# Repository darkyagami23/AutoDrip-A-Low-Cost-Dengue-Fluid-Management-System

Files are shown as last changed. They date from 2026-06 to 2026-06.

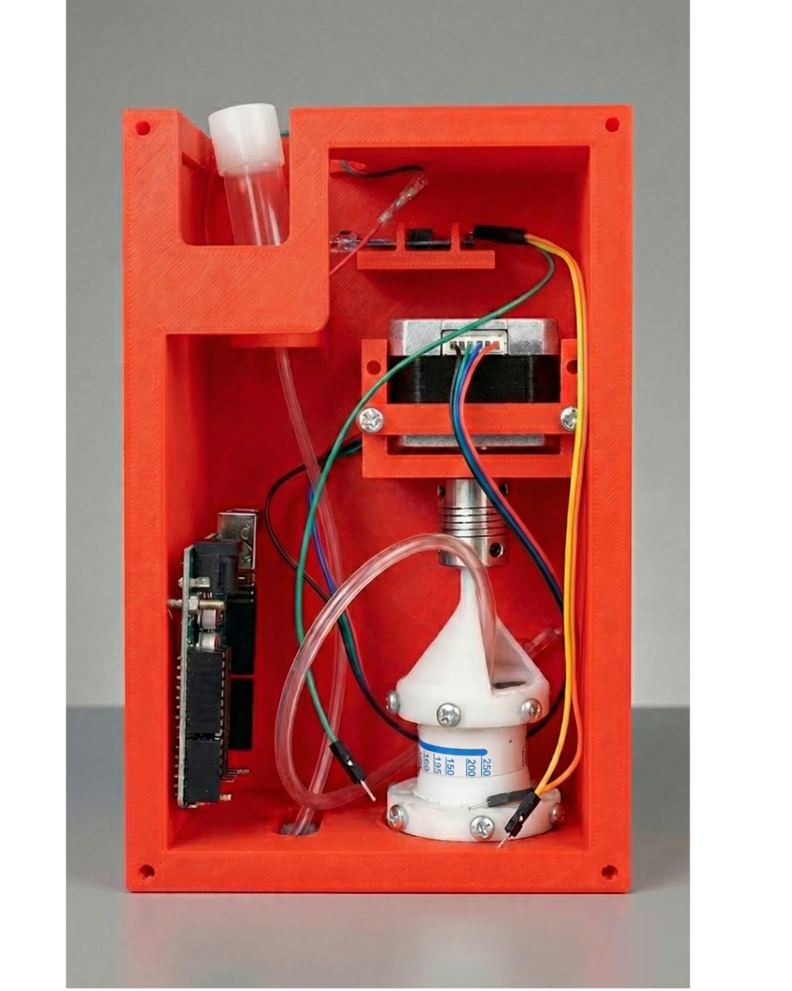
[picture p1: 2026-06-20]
docs/inside the box.jpg

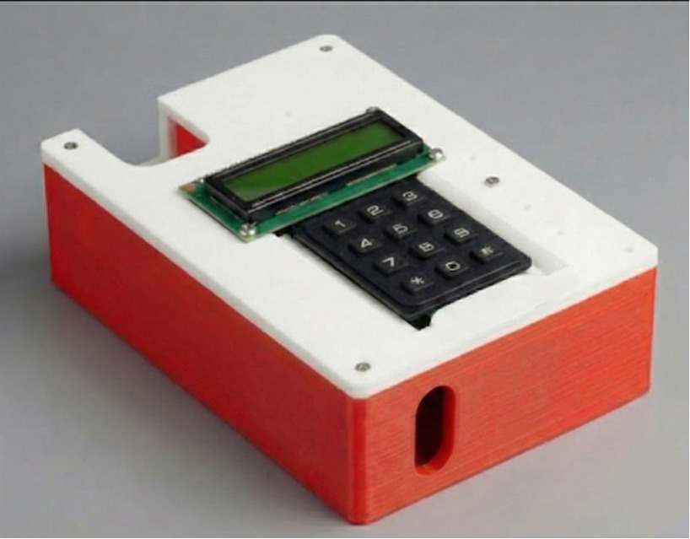
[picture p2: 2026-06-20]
docs/outside the box.jpg

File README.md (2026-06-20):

# AutoDrip: A Low-Cost Dengue Fluid Management System

## Overview
AutoDrip is a low-cost, gravity-driven automated controller designed to calculate required flow rates and regulate clinical flow rates for Group B dengue patients. The device ensures accurate, safe, and standardized intravenous (IV) fluid delivery in resource-constrained healthcare environments. 

## System Architecture
The system integrates four primary components:
*   A flow calculator based on national dengue guidelines.
*   A non-contact infrared (IR) drop sensor.
*   A stepper-actuated flow regulator (Nema 17).
*   A binary search-based feedback algorithm.

## Hardware Requirements
*   Microcontroller (e.g., ESP32 / Arduino)
*   Nema 17 Stepper Motor (17HS4401S)
*   Non-contact IR Sensor (LED emitter and photodiode receiver)
*   Standard Dial Flow Meter
*   3D Printed Parts: Conical Coupler and Fixer (Files located in `/CAD`)

## Software Installation
1. Clone this repository.
2. Open the `/firmware` directory in your preferred IDE.
3. Flash the firmware to the microcontroller. 

## Citation
If this project aids your research, please cite the original ICME 2025 paper:
> Ahasan, M. M., Shaikh, N. A., Himel, S. S., & Ahmed, M. T. (2025). *AutoDrip: A Low-Cost Dengue Fluid Management System*. 15th International Conference on Mechanical Engineering (ICME 2025).

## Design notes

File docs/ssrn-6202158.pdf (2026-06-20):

ICME 2025

Paper ID 286 – 1

# AutoDrip: A Low-Cost Dengue Fluid Management System

## Mir Mashrafi Ahasan¹, a), Nuzhat Aisha Shaikh¹, b), Sadman Sakib Himel ¹, c) and Md. Tazuddin Ahmed¹, d)

1Department of Biomedical Engineering, Bangladesh University of Engineering and Technology, Dhaka-1205, Bangladesh

a) Corresponding author: 2018023@bme.buet.ac.bd b)2018022@bme.buet.ac.bd
c)2018013@bme.buet.ac.bd
d) mdtuahmed@bme.buet.ac.bd Abstract. Dengue fever is a major health concern in subtropical regions, where severe cases require precise intravenous (IV) fluid therapy to prevent life-threatening complications. In resource-limited settings, manual drip regulation is error-prone due to staff shortages and inadequate monitoring. AutoDrip, an automated gravity-driven fluid management system, is presented to calculate the required flow rate (RFR) and regulate the clinical flow rate (CFR) for dengue patients. The device combines a stepper motor–driven flow controller, a non-contact infrared (IR) drop sensor, and a binary search–based feedback algorithm. System performance was evaluated under dengue IV therapy protocols. The RFR calculation achieved 100% accuracy, drop count accuracy averaged 98.3%, and CFR regulation reached 99.3% accuracy, stabilizing within 7-9 iterations. These results demonstrate that precise and reliable infusion control can be achieved with a low-cost device, making AutoDrip a practical solution to enhance patient safety and reduce clinical workload during dengue outbreaks.

KEY WORDS: Automated IV therapy, Dengue fluid management, Medical device automation, Healthcare resource optimization, Point-of-care technology

### 1. INTRODUCTION

Dengue is a major public health concern in tropical regions such as Bangladesh, with 321,073 cases recorded in 2023—the country’s largest outbreak to date [1]. Severe cases require precise intravenous (IV) fluid therapy, yet manual regulation with gravity sets is highly error-prone, often deviating by ±20–25%, particularly during patient surges that strain nursing capacity. Infusion pumps provide accurate delivery but remain costly and impractical in resource-limited settings.

Several automated infusion systems have been proposed, using optical, ultrasonic, or pressure sensors with servo or peristaltic pump mechanisms [2–4]. Al-Obaidi et al. (2024) developed an Intelligent Saline Controlling Valve utilizing a Mamdani fuzzy inference system to autonomously regulate intravenous fluid rates and prevent air embolisms by monitoring drip speed, pressure, and bubble presence [5]. Pabitha and Selvakumar (2025) proposed an IoT-enabled architecture facilitating real-time remote monitoring of IV fluid levels and automated alerting via a mobile application [6]. Gravity-based solutions such as AccuDrip demonstrate improved stability over manual regulation [7]. However few designs specifically target dengue requirements or include formal tolerance and convergence analysis. To address this gap, we propose AutoDrip, a low-cost, gravity-driven automated controller. The system integrates (i) a flow calculator based on national dengue guidelines, (ii) a non-contact infrared drop sensor, (iii) a stepper-actuated flow regulator, and (iv) a binary search–based feedback algorithm. AutoDrip is designed to ensure accurate, safe, and standardized fluid delivery for Group B dengue patients in resource-constrained healthcare environments.

15th International Conference on Mechanical Engineering 17-18 December 2025, BUET, Dhaka, Bangladesh

Available on SSRN. SSRN is an open-access online preprint community, owned by Elsevier.

This preprint research paper has not been peer reviewed. Electronic copy available at: https://ssrn.com/abstract=6202158

# Preprint not peer reviewed

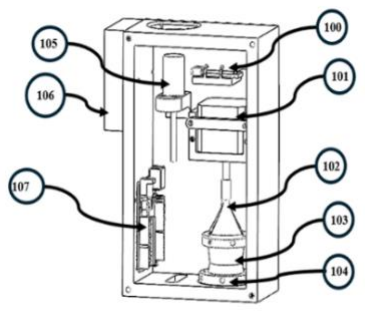
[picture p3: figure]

Paper ID 286 – 2

### 2. METHODOLOGY

### 2.1 FLOW RATE CALCULATION

### 2.1.1 Clinical Classification of Dengue Patients

Dengue, an arboviral disease, istransmitted by Aedes mosquitoes. Patients are stratified as Group A (mild), Group B (warning signs or risk factors requiring hospitalization), and Group C (severe, needing intensive care) [8,9]. This system targets Group B dengue patients, who require guided IV fluid therapy based on national clinical guidelines [8-10].

### 2.1.2 Calculation Principle

For Group B dengue patients, fluid requirement is calculated from demographic and clinical inputs (age, sex, height, body weight, blood pressure, capillary refill time, and IV set drip factor). Eligibility is confirmed when pulse pressure >20 mmHg and capillary refill time <2 s [1]. Maintenance fluid is then determined using the Holliday–Segar method, with actual body weight applied when BMI ≤25, otherwise IBW (Ideal Body Weight) is derived from the formula of equation (1) and (2),
Men: 50 + max (0, 0.91 × [Heigℎt (cm)− 152.4]) kg | (1)
Women: 45.5 + max (0, 0.91 × [Heigℎt (cm)− 152.4]) kg | (2)
Maintenance and Deficit Fluid Requirement
The Holliday–Segar 4-2-1 rule was used: 4 mL·kg⁻¹·h⁻¹ for the first 10 kg, 2 mL·kg⁻¹·h⁻¹ for the next 10 kg, and 1 mL·kg⁻¹·h⁻¹ thereafter. Deficit Fluid Requirement (Oral+IV) for ‘Group-B NS’ patients, a default 5% dehydration is assumed in equation (3):
Deficit fluid (mL) = 50 mL ∙ kg⁻¹ × Wtparam(kg) (3)

Flow rate prescriptions follow the national dengue guideline, with reassessment every 6 hours for at least 48 hours. [9]

### 2.2 FLOWRATE COUNTER

The AutoDrip device monitors IV drip rates using a non-contact infrared (IR) sensor composed of an LED emitter and photodiode receiver. With the fall of each droplet, the LED is interrupted, generating a signal for drop counting. Since drop rates are uniform, continuous long-term monitoring is unnecessary. Tests with different averaging windows (5–20 s) showed that 10 s (Tavg) provides stable and accurate measurement. Drop counts are recorded in drops/s and converted to drops/min for comparison with prescribed rates. This method avoids contamination and integrates seamlessly with standard IV sets without modification.

### 2.3 FLOW CONTROL MECHANISM

The core of the AutoDrip system is its automated flow rate control mechanism, which translates digital calculations into precise mechanical adjustments of the intravenous (IV) fluid flow.
The primary components of the Flow Control Mechanism are:
- Stepper Motor(101): The final AutoDrip device employs a Nema 17 stepper motor (17HS4401S) with 600-step precision for flow control. The stepper, coupled with a custom conical coupler and dial flow meter, ensures reliable and accurate performance.
- Dial Flow Meter (114): The system uses a medically approved rotational dial flow meter to regulate IV tube constriction. While its built-in scale is not used for setting flow rates, the device ensures safe and reliable regulation as part of the AutoDrip system.

FIGURE 1 Isometric View of AutoDrip Device Assembly

# Preprint not peer reviewed

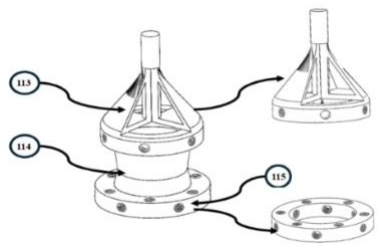
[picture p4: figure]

Paper ID 286 – 3

- Conical Coupler (113): A custom conical coupler connects the stepper motor to the dial flow meter, ensuring balanced torque transfer with minimal friction.
- Fixer (115): To ensure stability and prevent misalignment during rotation, a fixer is used to immobilise the stationary lower part of the dial flow meter assembly within the device housing.

### 2.4 FEEDBACK AND CONTROL ALGORITHM

### 2.4.1 Problem setup

Let θ ε [θmin, θmax]denote the motor angle controlling the tube constriction, and let f(θ) represent the steady-state drop rate measured by the IR sensor (drops/min). The clinical target is ft
. Within the operating region of interest, the mechanism behaves monotonically; that is, if θ1 < θ2

, then f(θ1

) ≥ f(θ2

). The objective is to
determine an angle θt
such that | f(θt

) − ft
| ≤ δ , where δ is a tolerance derived from clinical acceptance. With stepper-driven actuation, the admissible set of angles is shown in equation (4):
Θ = {θmin +kc | k = 0,1,2, ⋯ , N − 1}, N = ⌈

θmax−θmin
∆θ
⌉ | (4)

### 2.4.2 Binary search controller

Define the signed error e(θ) = f(θ) −ft

. With monotonic f(θ), the domain partitions into regions above or below the target. The binary search algorithm proceeds on the index interval [L, R] ⊆ {0,1,2, ⋯ , N − 1}:

1. Initialize L = 0, R = N −1
2. While L ≤ R:
i. M = ⌊

L + R
2

⌋ → set θ = θmin + M∆θ.

ii. Measure f(θ). (Averaged over a window Tavg)
iii. If | f(θt
) − ft

| ≤ δ → return θ
iv. If f(θ) > ft

: increase constriction → set L = M +1
v. Else: decrease constriction → set R = M − 1

### 2.4.3 Stabilisation Time

Each evaluation consists of, Teval = Tmove + Tsettle +Tavg. Each iteration of the algorithm halves the interval, keeping number of measurements K bounded by, ⌈log2 N⌉. Since averaging dominates (Tavg ≈10s window to smooth drop-count noise), the stabilization time, Tbin is bounded by, ⌈log2 N⌉ ∙ Teval .

Illustration for a 300° dial range with ∆θ = 1° where, N ≈ 300, K ≤ ⌈log2 300⌉, Teval ≈ 10s

FIGURE 2 Controller-Coupler Mechanism

FIGURE 3 Internal view (left) and external view (right) of the assembled device

# Preprint not peer reviewed

Paper ID 286 – 4

Tbin ≲ 9 ∗ 10 = 90s | (5)

### 2.4.4 Step-Size Adequacy and Angle-Flow Relation

The binary search algorithm operates in ∆θ = 1° increments, requiring verification that such steps remain within clinical tolerance. Let Q(θ) be the flow rate (mL ∙ ℎ

−1
) and the step size can be determined from equation (6):

S1° = |Q(θ +1°)− Q(θ)|, Smax = max
θ
S1°(θ) | (6)

The step size safety condition is therefore,

Smax ∙ ∆θ ≤ τQt

, τ = 0.05(±5%) | (7)

With Qt being the target flow-rate consistent with infusion pump standards. From the dial curve in fig. 4, Smax ≈ 5 mL ∙ ℎ

−1 near 225–250 mL ∙ ℎ

−1
. Table 2 confirms that increments across 50–250 mL ∙ ℎ
| −1 remain well within
±5%, with deviations only 0.5–2.1% per degree.

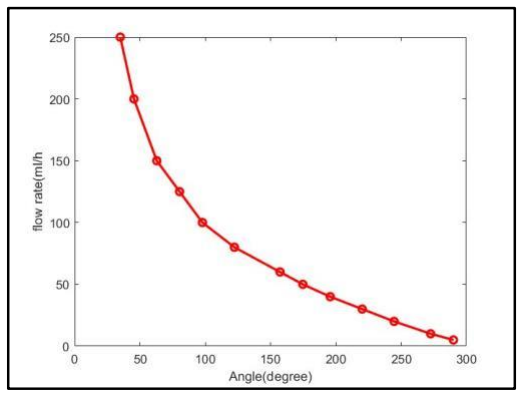
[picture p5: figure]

Target Flow Qt (mL/h) | ±5% Tolerance Band (mL/h) | Observed ∆Q per 1° (mL/h)
50 | ±2.5 | 0.5
100 | ±5 | 1.0
200 | ±10 | 2.5
250 | ±12.5 | 5.0

A fitted power law model can be given like equation (8), Q(θ) = a(θ − θ0)

−b

, a = 6.24 × 10⁹
, b = 3.22, θ0 = −163.5°, R
2 = 0.992 | (8)
Further supports this. For 1° step, the relative change per degree simplifies to equation (9),

1
Q

dQ
dθ| =

b
θ−θ0

(9)

predicting relative slopes of 0.7–1.6% per degree over the measured range. Both empirical and modeled results

confirm that the 1° step resolution is clinically safe.

### 2.4.5 Effect of Height (hydrostatic head)

For gravity infusion, height scales the entire angle–flow curve multiplicatively following the eq (10).

Q(θ, ℎ) = K(ℎ) ∙ a(θ −θ0)

−b
, K(ℎ) ∝ (ℎ− ℎv)

α
, α ε [0.5,1] (10)

where ℎ is the fluid level above the vein, and ℎv is the effective venous pressure height. The relative slope can be determined from equation (11)

FIGURE 4: Flow-rate vs angle curve of a standard Dial-a-Flow regulator.

TABLE 2: Safety check for 1° steps across target flows

# Preprint not peer reviewed

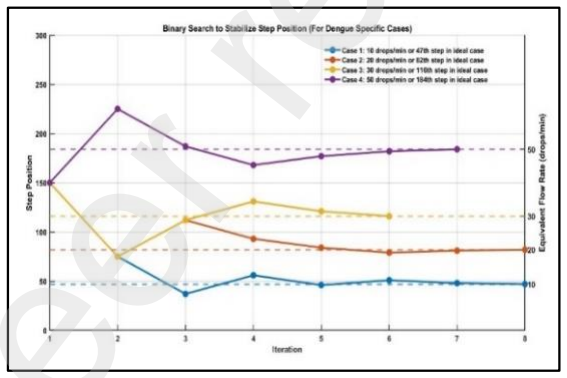
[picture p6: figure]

Paper ID 286 – 5

1
Q

dQ
dθ| =

K(ℎ)∙ab(θ−θ0)

−b−1
K(ℎ)∙a(θ−θ0)⁻b =

b
θ−θ0

(11)

showing that the percentage change per degree is independent of height. Therefore, the 0.71–1.62% per-degree range holds for all clinically relevant heights.

### 3. RESULTS

### 3.1 Flow Rate Detection Accuracy

The IR-based drop counter was validated against manual observation at four flow settings (10, 20, 30, and 50 drops/min). Figure 5 shows an almost perfect linear correlation between sensor output and manual counts (R

2 ≈
0.998), confirming reliable drop detection. Deviations were minimal, with IR readings differing from manual counts by at most ±2 drops/min. This demonstrates that the non-contact optical sensor provides accurate and sterile monitoring of IV flow rates in the clinically relevant range.

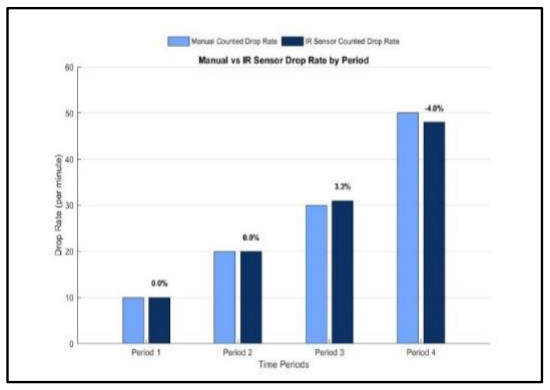
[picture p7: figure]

### 3.2 Feedback Loop Convergence

The closed-loop binary search controller consistently stabilized the infusion flow to within ±5% of the prescribed rate. Convergence occurred within 5–9 iterations, corresponding to a worst-case stabilization time of 90s (Figure 6). This aligns with theoretical predictions in equation (5) and demonstrates the efficiency of binary search compared to sequential or proportional methods. The evaluation was carried out under ideal-case conditions for dengue-specific flow rates, ensuring that the results directly reflect the clinical use scenario.

### 3.3 Step-Size Tolerance Analysis

Analysis of the angle–flow curve showed that the steepest region (225–250 mL/h) produced a maximum step sensitivity of ~5 mL/h per 1°, corresponding to ~2.1% of the flow at that setting. Across the full 50–250 mL/h range, relative deviations per degree remained between 0.7% and 2.1%, well within the ±5% tolerance band. Thus, the 1° actuator resolution is adequate for all clinically relevant infusion rates.

4.DISCUSSION

The closed-loop controller reliably converged within ±5% of prescribed dengue-specific infusion rates (10–50 drops/min, equivalent to 40–200 mL/h), stabilising in fewer than nine iterations (~90 s). Even under an edge case

FIGURE 5: Manual vs IR sensor drop rate detection by period

FIGURE 6: Binary Search to stabilize Step position (For dengue specific cases)

# Preprint not peer reviewed

Paper ID 286 – 6

of ~4% flow count error around 180–200° on the dial, the relative sensitivity was only ~0.9% per degree—well below the tolerance band. At the upper end (200 mL/h, 50 drops/min), the steepest step sensitivity observed was ~2.1% per degree, which also remains within safety limits. Together with ±2 drops/min sensor accuracy, these results confirm that the system maintains safe operation across the entire dengue treatment range.

Clinically, this performance is significant as manual gravity regulators deviate by ±20–25%, whereas AutoDrip achieves pump-grade accuracy using only low-cost hardware. The ~90 s stabilization period derived in equation
(9) is negligible in practice, as dengue infusion protocols reassess and modify flow rates at 6-hour intervals [9]; therefore, a 1.5 minute convergence has no meaningful impact on total fluid administration. Although bag height influences the hydrostatic head, the controller adaptively compensates for these changes by adjusting constriction to maintain the prescribed flow rate. Consideration of venous back-pressure effects was beyond the scope of this study.

### 5. CONCLUSION

In conclusion, this project successfully demonstrates AutoDrip as a cost-efficient automated infusion system that addresses the critical challenge of precise fluid management for dengue patients, particularly in resource-constrained settings. By integrating non-contact IR sensing for real-time drop detection with a stepper motor-driven feedback controller, the system achieves remarkable accuracy and reliability. The results confirm the system's clinical significance. The feedback loop consistently converges to within ±5% of the prescribed rate, while the IR sensor maintains a minimal deviation of at most ±2 drops/min. This performance represents a transformative improvement over manual gravity regulators, which commonly deviate by a hazardous ±20–25%. Furthermore, a step-size tolerance analysis revealed that the system's mechanical sensitivity remains between 0.7% and 2.1% per degree, ensuring stability and safety even at steeper flow regions. These outcomes collectively emphasize the critical role of accessible automation in elevating IV fluid management to a reliable, pump-grade process without the high cost. Ultimately, integrating this technology into clinical practice has the potential to alleviate critical personnel shortages, enhance the standard of care, and provide a tailored, scalable solution to mitigate the burden of dengue epidemics.

### 6. REFERENCES

1. DGHS Bangladesh. Dengue Situation Report, 2023. https://dashboard.dghs.gov.bd/pages/heoc_dengue_v1.php
2. Das A, Kumar A, Patel S, et al. Automated IV Infusion Control System Design and Development for Medical Use. Int J Eng Sci Res Tech. 2023;12(1):45-50.
3. Rahman S, Chowdhury M, Uddin J, et al. Design of an Automated Intravenous Fluid Monitoring System Using IR Sensors. Proc Int Conf Biomed Eng. 2021; p. 122-126.
4. Al-Shargabi B, Alshammari T, Alanazi A, et al. Smart Intravenous Infusion Monitoring Systems: A Review. Sensors. 2022;22(15):5632.
5. Al-Obaidi, A.S.I., Al-Nima, R.R.O. & Qassim, H.M. Intelligent saline controlling valve based on fuzzy logic. J. Eng. Appl. Sci. 71, 163 (2024).
6. P. Pabitha and J. Selvakumar, "IoT-Enabled Real Time Intravenous Monitoring and Alert System for Healthcare Management," in 2025 International Conference on Advanced Computing Technologies (ICOACT), Sivakasi, India, 2025, pp. 1–8, doi: 10.1109/ICOACT63339.2025.11005176.
7. Kim J, Park S, Choi H, et al. AccuDrip: A Gravity-Driven Automated Infusion Device for Stable IV Delivery. Biomed Eng Online. 2024;23:57.
8. WHO. Dengue: Guidelines for Diagnosis, Treatment, Prevention and Control. Geneva: World Health Organization; 2009.
9. DGHS Bangladesh. National Guideline for Clinical Management of Dengue Syndrome, 2018.
10. Guzman MG, Harris E. Dengue. Lancet. 2015;385(9966):453–465.

# Preprint not peer reviewed

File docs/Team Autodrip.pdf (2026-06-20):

# A Low Cost Automated Dengue Fluid Management System

# Abstract

# Methodology

# Auto-Drip

Sadman Sakib Himel, Nuzhat Aisha Shaikh, Mir Mashrafi Ahasan Supervisor : MD Tazuddin Ahmad

Dengue fever, caused by the dengue virus, leads to complications like plasma leakage, which can result in shock and organ failure if not managed properly. Effective fluid management is critical for Type B
dengue patients to maintain blood volume.

However, Bangladesh faces severe healthcare manpower shortages, with a population-to-nurse ratio of 5000:1 and a bed-to-nurse ratio of 13:1, making timely treatment difficult.

Fig 2 : Device Morphology

Dengue fever remains a significant public health concern especially in this subtropical region, and the need for effective and cost-efficient solutions to manage its complications is increasingly pressing. In 2023, Bangladesh witnessed its highest number of dengue-related deaths in 23 years, with 321,179 hospitalizations and 1,705 fatalities. As of June 28, 2025, there have been 9,484 dengue cases and 41 deaths reported this year.
Although effective fluid management is critical for treating dengue patients, frequent monitoring of IV flow rates is challenging due to limited healthcare personnel. To address this issue, we have developed AutoDrip, an advanced Dengue Fluid Management System designed to automate and optimize IV fluid delivery. The system automates IV fluid management by:
•Detecting the current flow rate using an IR sensor. •Calculating the required flow rate based on patient vitals or user input.
•Adjusting the flow rate automatically via a stepper motor.
The system features two modes: normal mode and dengue mode.

IR Sensor Validation: The graph shows the IR sensor's drop detection with minimal error, confirming its accuracy in comparing actual and expected rates, forming the basis of the feedback system.

Binary Search Algorithm Validation: The graph illustrates that the algorithm reaches the target flow rate within 8 iterations for all test cases, highlighting its efficiency.

Flow Rate Calculation: The graph shows that the device’s 48-hour flow rate matches the output of the DGHS-approved Dengue Drops App, validating its reliability.

Methodology | Result & Analysis

# Problem Statement

Fig 7 : Drop Rate manual vs IR sensor

Fig 9: Data validation by Dengue Drops app

Arduino

Power Source

Stepper Motor

Controller

IR Sensor

## Device Description

2) Flowrate Detection:

A non-contact Infrared (IR) Sensor is positioned on the IV drip chamber to provide real-time measurement of the current drop rate (drops/minute).

3) Automated Control and Feedback Loop:
- The system's core logic compares the real-time rate from the IR sensor to the desired target rate.
- A Binary Search Algorithm is implemented to efficiently find the correct rotational position for the stepper motor, allowing the system to rapidly converge on the target flow rate (typically within 8 iterations).

Fig 3 :IR Sensor

Fig 6 : Flowrate Controller

4) Flowrate Control:

We rejected linear constriction methods (like rack and pinion) due to torque and stability issues. The final design uses a Stepper Motor to precisely rotate a standard, off-theshelf Dial Flow Controller. A custom 3Dprinted Conical Coupler was designed to ensure a strong, perfectly aligned connection between the motor and the dial.

5) Fail-Safe System:
- Device Fall Detection:
If the device accidentally falls, an Accelerometer detects the movement and sends an immediate notification, ensuring prompt corrective action.
- Saline Bottle Monitoring:
The system monitors the saline bottle and alerts the user when it is empty. This prevents interruptions in fluid delivery, especially during critical treatments..

The device has the potential to revolutionize the automation of our healthcare system. It offers a simple yet highly efficient solution to address challenges during pandemic situations. Equipped with a responsive feedback mechanism, the device can seamlessly adapt to any abrupt changes in flow rate, ensuring consistent and accurate fluid delivery. Furthermore, its embedded alert system proactively notifies users of any issues, guaranteeing safety and reliability. With these features, the device stands out as a safe, effective, and indispensable tool for modern healthcare settings.

# Discussion

## Reference & Acknowledgement

Fig 1 : THE BUSINESS STANDARD,Kamran Siddiqui, 02-05-2020

1) Desired Flow Rate Determination

❑ Normal Mode: Allows clinicians to manually input a specific flow rate using an integrated keypad.
❑ Dengue Mode: Automatically calculates the optimal
flow rate based on patient vitals (e.g., weight, patient
type) to comply with clinical guidelines. | USP
User-Centered, Intuitive
Design for Maximum
Adoption

Plug-and-play
compatibility with
current hospital
setups, with futureready EHR integration.

Scalable and affordable,
built for high-demand,
low-resource
environments

Built-in fail-safes ensure uninterrupted operation
with instant
manual override.

Automated system frees
up critical staff through
intelligent resource
allocation

Real-time adaptive
control ensures precise,
delay-free fluid
management

Fig 4 : Flowrate of the working principle

Fig 8 : Validation of Binary Search Algorithm

Fig 5 : Final Device

## Unique Selling Point

### 1. Special Thanks to-

Dr. Md. Khairul Islam
MBBS, BCS(Health), MCPS(Medicine), FCPS(Medicine) Dhaka Medical College Hospital, Dhaka

### 2. National Guideline for Clinical Management of Dengue

Syndrome- 4

th Edition, 2018 (Revised)
3. https://old.dghs.gov.bd/index.php/bd/home/5200-dailydengue-status-report (https://old.dghs.gov.bd/index.php/bd/home/5200-daily-dengue-status-report)
4. https://www.who.int/emergencies/disease-outbreaknews/item/2023-DON481 (https://www.who.int/emergencies/disease-outbreak-news/item/2023-DON481)
5. THE BUSINESS STANDARD,Kamran Siddiqui, 02-05-2020

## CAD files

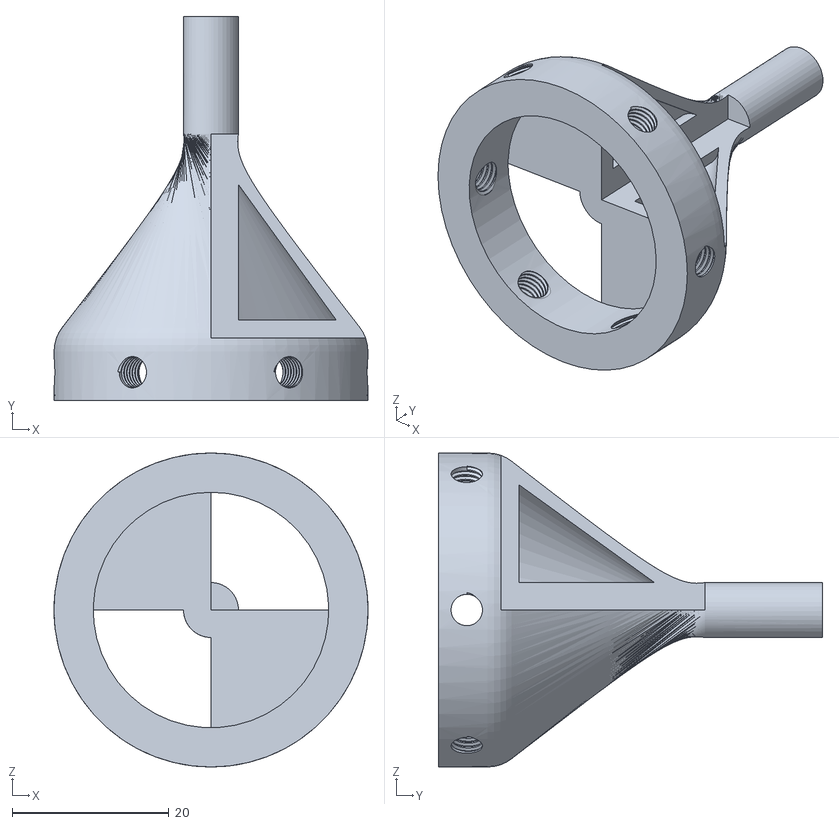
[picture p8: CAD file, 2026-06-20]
CAD/Conical_coupler.STL
40.0 x 49.0 x 40.0

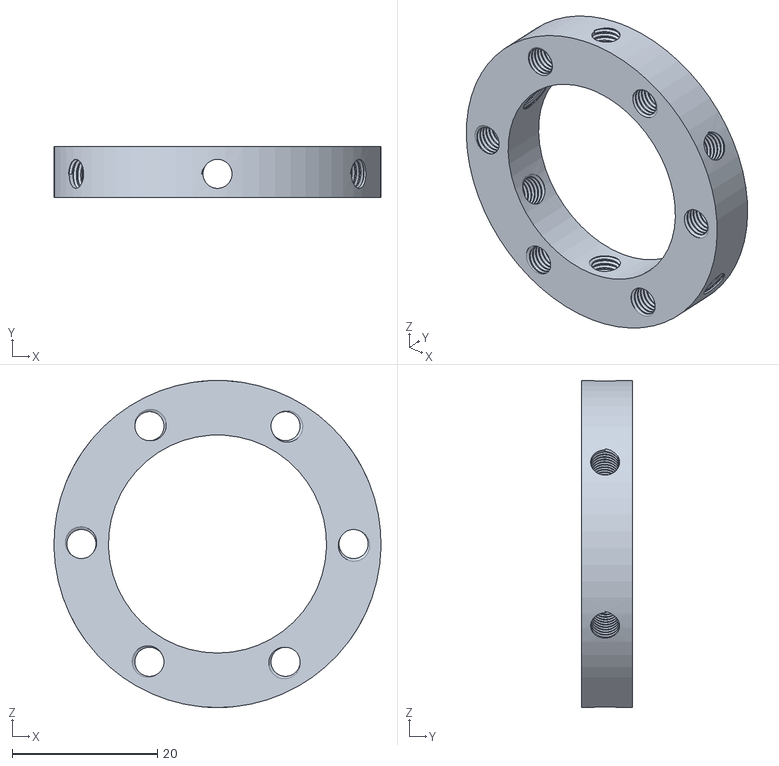
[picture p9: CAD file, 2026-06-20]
CAD/Fixer Part.STL
45.0 x 7.00 x 45.0

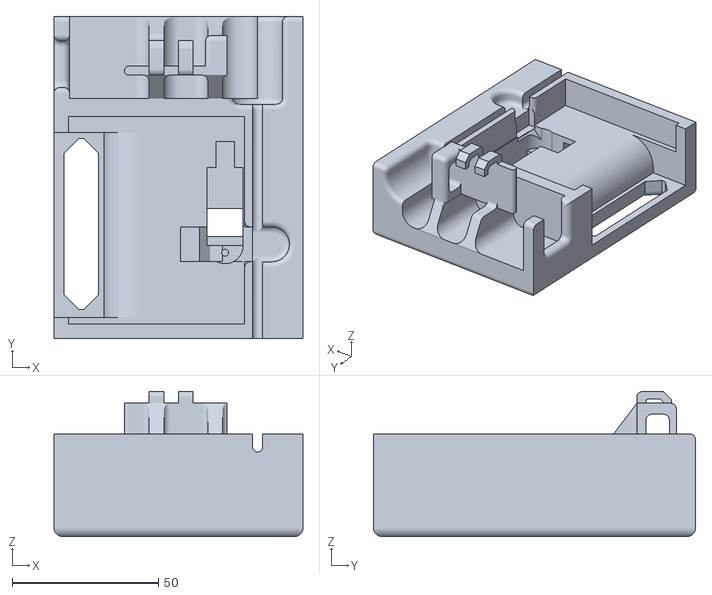
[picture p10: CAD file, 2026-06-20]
CAD/Device Box.STL
85.0 x 110.0 x 49.5

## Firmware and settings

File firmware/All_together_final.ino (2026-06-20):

  #include <Arduino.h>
  #include "A4988.h"
  #include <LiquidCrystal_I2C.h>
 
  // Define pins for the stepper motor
  int Step = 3;  // Step pin
  int Sleep = 4;
  int Dire = 2;  // Direction pin
  int MS1 = 7;   // Microstep pin MS1
  int MS2 = 6;   // Microstep pin MS2
  int MS3 = 5;   // Microstep pin MS3

  // Motor specifications
  const int spr = 200;  // Steps per revolution (200 for full-step mode)
  int RPM = 25;         // Motor speed in RPM
  int Microsteps = 3;   // Full-step mode

  // Initialize stepper motor with A4988 driver
  A4988 stepper(spr, Dire, Step, MS1, MS2, MS3);

  // Binary search variables
  int low = 0;          // Initial lower range
  int high = 450;       // Upper range (200 steps per revolution)
  int count = 0;        // Iteration count
  int currentStep = 0;  // Current step position
  int prevGuess = 0;    // Previous guess

  double Stab_duration=30.0;     //stabilization duration

  LiquidCrystal_I2C lcd(0x27, 16, 2);
  // IR sensor variables
  volatile unsigned long time_begin;
  volatile unsigned long time_end;
  volatile int EFR;
  volatile int duration_sec;
  volatile int state;
  volatile int x =0;
  volatile double flow_rate = 0;
  volatile int prev = 0;

  void setup() {

    Serial.begin(9600);
    //Serial.println("Started");
    pinMode(Step, OUTPUT);    //Step pin as output
    pinMode(Dire, OUTPUT);    //Direcction pin as output
    pinMode(Sleep, OUTPUT);   //Set Sleep OUTPUT Control button as output
    digitalWrite(Step, LOW);  // Currently no stepper motor movement
    digitalWrite(Dire, HIGH);
    digitalWrite(Sleep, HIGH);  //A logic high allows normal operation of the A4988 by removing from sleep
    delay(1000);                //Wait 1000 milliseconds (1 second) proceeding
    // Set target motor RPM to and microstepping setting
    stepper.begin(RPM, Microsteps);
    //Serial.println("Outof setup");
  }

  // Function for measuring flowrate using IR that returns up or down or stop
  int measureFlowRate(float efr) {
    time_begin = micros();

    //Serial.println("flow rate loop");
    while (duration_sec <= Stab_duration) {
      //Serial.println("inside while loop  ");
      int counter = digitalRead(A0);
      if (state == 0) {
        switch (counter) {
          case 1:
            state = 1;
            x = x + 1;      
            //Serial.println("Drop count increased  ");
            break;
          case 0:
            state = 0;
            break;
        }
      }

      if (counter == LOW) {
        state = 0;
      }
      time_end = micros();
      //duration=time_end - time_begin;
      duration_sec = (time_end - time_begin) / 1000000.0;
    }
    flow_rate = (x / Stab_duration)*60;
    //Serial.println("flow rate changed");
    time_begin = time_end;
    x = 0;
    duration_sec = 0;

    if (efr < flow_rate) {
      return 1;
    } else if (efr > flow_rate) {
      return 2;
    } else if (efr == flow_rate) {
      return 3;
    }
  }

  // BInary search Function
  int binsearch(int low, int high) {
    // Perform binary search
    int guess = (low + high) / 2;
    int stepsToMove = (guess - currentStep);  // Calculate the difference in steps

    stepper.move(stepsToMove);                 // Move the motor by the calculated steps          // Update the current position

    delay(500);  // Allow time for the motor to stabilize
    // Serial.print("Current guess: ");
    // Serial.println(guess);
    // Serial.print("Steps to Move: ");
    // Serial.println(stepsToMove);

    return guess;
  }


  void loop() {
    // put your main code here, to run repeatedly:
    
    // Serial Input
    //Serial.println("Provide expected Flowrate : ");
    // int userInput = Serial.parseInt();
    // while (Serial.available() > 0) {
    //   Serial.read();  // Clear serial buffer
    // }

    Serial.println("In the loop");
    while(true) { // Check if data is available to read
      if(Serial.available()>0){
        //Serial.println("In the condition");
        String receivedData = Serial.readStringUntil('\n'); // Read until newline character
        EFR = receivedData.toInt(); // Convert the received data to an integer
        Serial.print("Received Number: ");
        Serial.println(EFR); // Print the received number
        break;
      }
    }
    //Serial.println("Out of the loop");
    // EFR = receivedNumber;
    // Inner loop to stabilize flowrate
    // Serial.print("EFR: ");
    // Serial.println(EFR); // Print the received number
    while (count<=8) {
      int flag = measureFlowRate(EFR);
      int currentGuess;
      if (flag == 1) {
        high = currentStep;
        currentStep = binsearch(low, high);
      } 
      else if (flag == 2) {
        low = currentStep;
        currentStep = binsearch(low, high); 
      }

      count++;

      // Serial.print("Iteration ");
      // Serial.print(count);
      // Serial.print(": Current step position approximation is ");
      // Serial.println(currentGuess);

      // Check if the approximation is within an acceptable range
  
      prevGuess = currentGuess;
    }

  }
